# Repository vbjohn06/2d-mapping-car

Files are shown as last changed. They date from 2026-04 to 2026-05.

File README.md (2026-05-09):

# Autonomous Mapping Robot (Differential Drive)

A Mechatronics engineering project designed to navigate a room perimeter autonomously and generate a 2D spatial map. The robot uses custom odometry math and ultrasonic projection to transform raw sensor data into a high-definition car path.

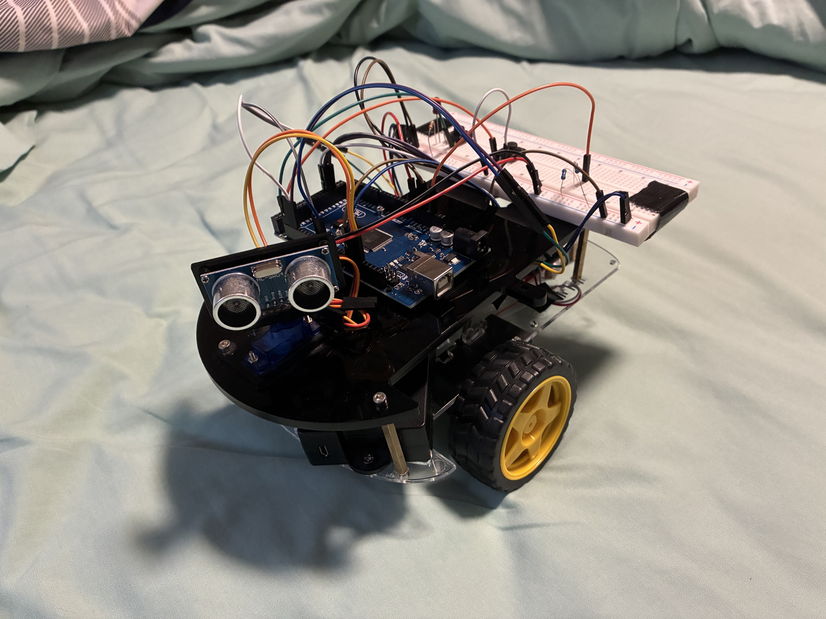
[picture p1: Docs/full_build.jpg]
Image of Car Build
| Robot Build |  |
| :---: | :---: |
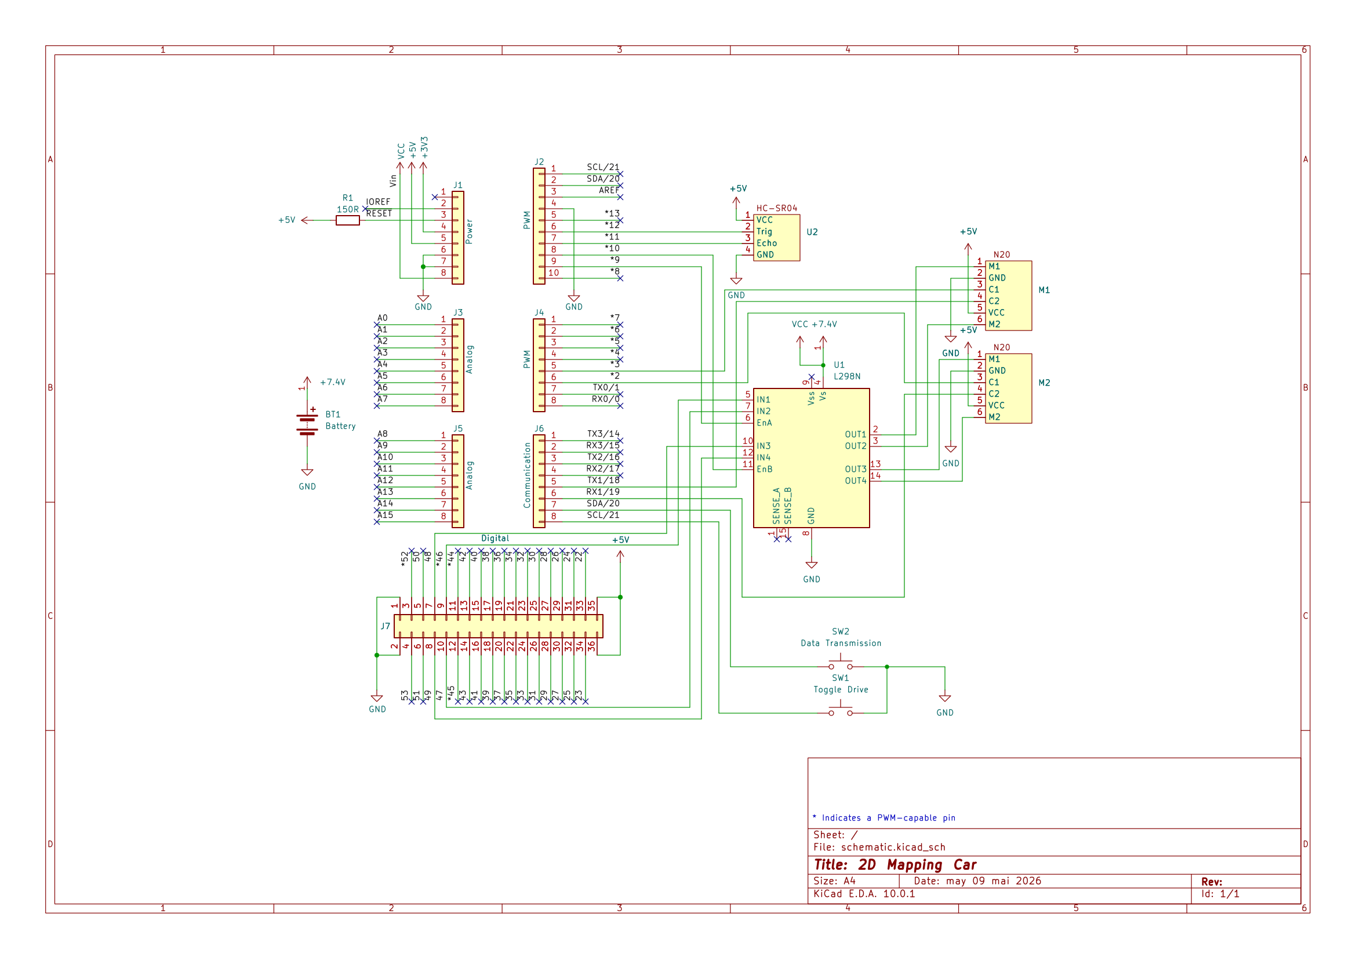
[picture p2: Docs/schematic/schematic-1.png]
Image of Car Schematic
| Robot Schematic |  |
| Live Demo | 2D Mapping Car Demo (https://youtube.com/shorts/CDQi3uIZbc0) |

## 🛠 Features
* **Differential Odometry:** Real-time tracking of $x$, $y$, and $\theta$ (heading) using high-resolution quadrature encoders.
* **Intelligent Wall-Following:** PD-style control logic to maintain a consistent 35cm safety buffer from obstacles using an ultrasonic sensor.
* **Data Logging:** Captures coordinates every 2.5 cm of travel, stored in a 400-point array for USB serial transmission.
* **Self-Correction:** Validated encoder polarity to ensure turns and straight-line distances are calculated with high precision.

---

## 🚀 Hardware Stack
* **Controller:** Arduino MEGA 2560 (ATmega2560)
* **Sensors:** HC-SR04 Ultrasonic Sensor, Dual Quadrature Encoders
* **Communication:** USB Serial Interface (115200 Baud)
* **Chassis:** Two-wheel differential drive (N20 encoder motors driven by L298N driver) with a front swivel caster
* **Power:** 7.4V Li-ion Battery Pack

---

## 💻 Control Logic (Finite State Machine)
The firmware cycles through three primary states to ensure reliable navigation:
1.  **ALIGNING:** Corrects the robot's heading relative to the side wall to maintain the set distance.
2.  **DRIVING:** Executes forward motion while recording points to the internal memory array.
3.  **STUCK:** Detects front-facing obstacles and executes a precision pivot turn to transition to the next wall.

---

## 📂 Project Structure
* `/Arduino`: Contains the `.ino` sketch for motor control, PID alignment, and odometry.
  * **Dependencies**: Requires the `Encoder.h` library by Paul Stoffregen.
  * **Installation**:
    1. Open the **Arduino IDE**.
    2. Go to **Sketch** -> **Include Library** -> **Manage Libraries...**
    3. Search for "Encoder" and look for the version by **Paul Stoffregen**.
    4. Click **Install**.
  * **Hardware Note**: Ensure your encoder pins are connected to interrupt-capable pins (e.g., Pins 2, 3, 18, 19, 20, 21) for the best performance.
* `/Python`: Visualization script to receive Bluetooth data and plot the resulting map using Matplotlib.
  * **Dependencies**: This script requires `matplotlib`, `numpy`, and `pyserial` to function.
  * **Installation**: Open your computer's system terminal (Command Prompt, PowerShell, or Terminal) and run the following command:
      ```bash
      pip install matplotlib numpy pyserial
      ```
* `/Docs`: Technical diagrams for sensor placement and coordinate system geometry.

---

## Technical Difficulties

* **Wireless Communication:** Initially attempted to utilize an **HC-05 Bluetooth module** to stream data and preserve Arduino SRAM. However, the module encountered persistent driver incompatibilities with the host laptop, necessitating a shift in data handling.
* **Hardware Failure:** During hardware integration testing, the **servo motor** controlling the ultrasonic sensor sweep experienced an electrical short. As a result, the sensor is currently in a fixed-forward position for the mapping logic.

---

## How to Run
1. Allow the car to follow the perimeter of the room.
2. Open the `map_plotting.py` file and wait for data transmission.
3. Press the data transmission button on the breadboard.
5. PNG file of the map output should open.

---

## 👤 Author
**Johnny Van Bakel** *Mechatronics Engineering Student* *McMaster University*

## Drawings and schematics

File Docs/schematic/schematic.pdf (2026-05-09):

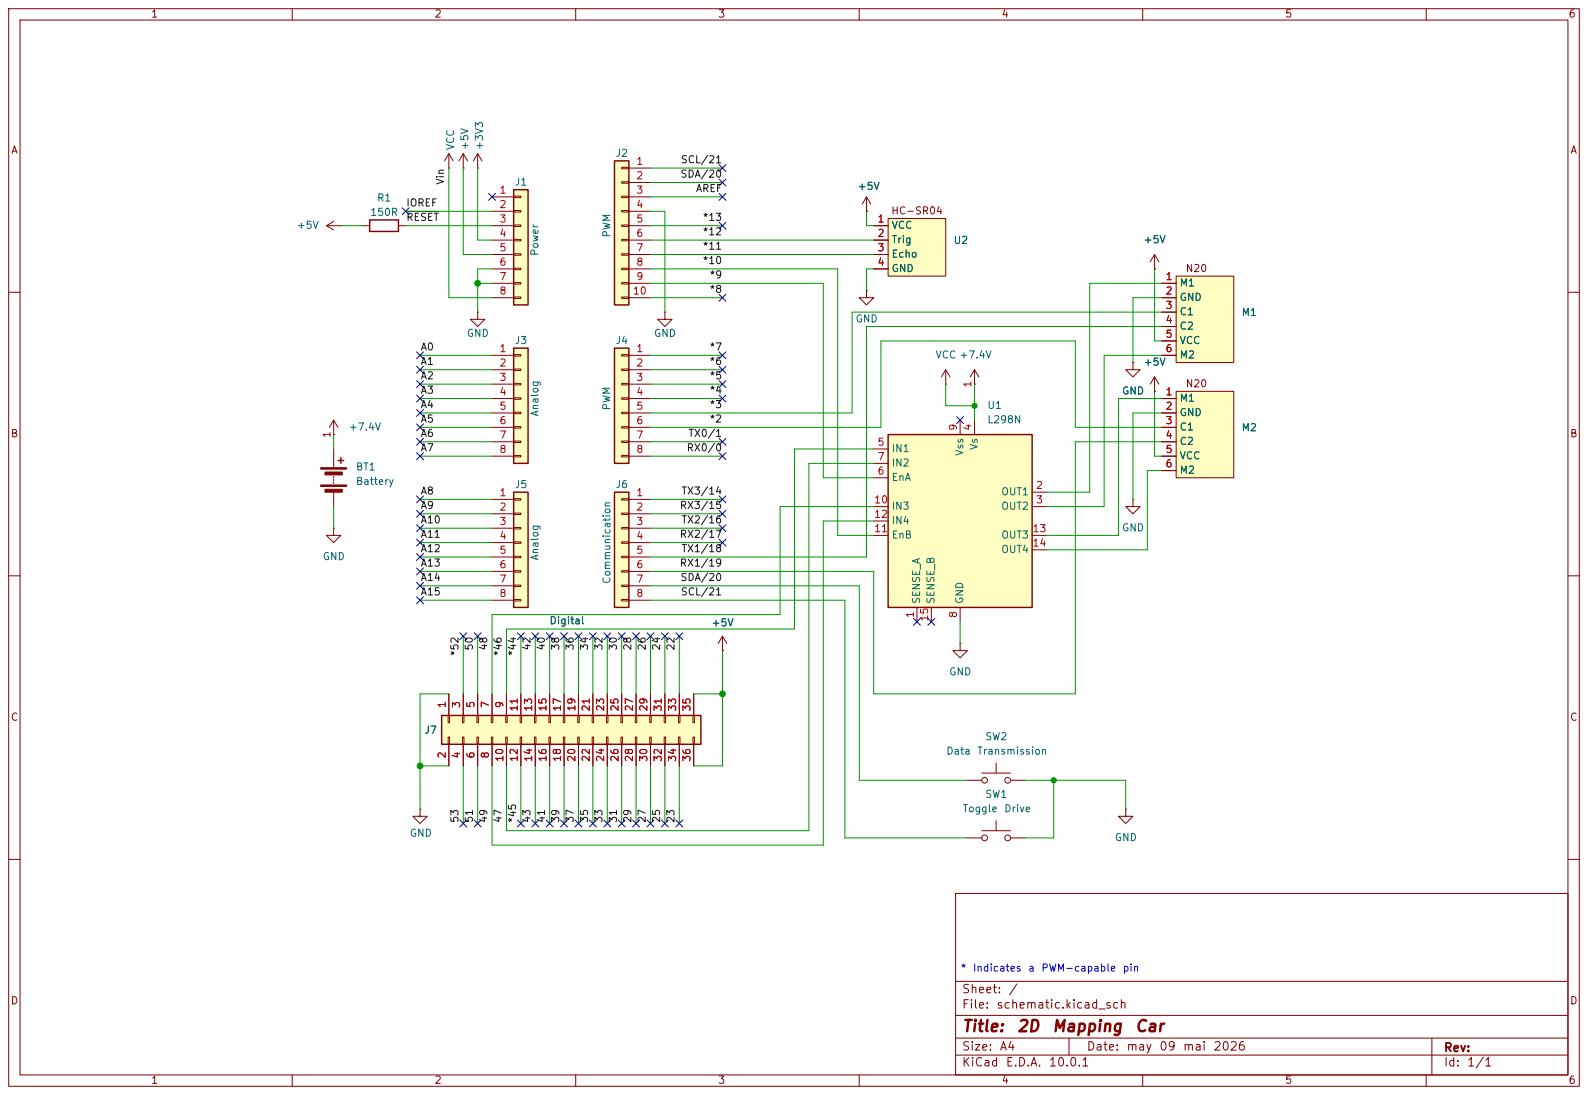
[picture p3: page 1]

*11
*10

GND 12345678

RX1/19
SDA/20
SCL/21

* Indicates a PWM-capable pin +5V

Size: A4 | Rev:
KiCad E.D.A. 10.0.1 | Id: 1/1

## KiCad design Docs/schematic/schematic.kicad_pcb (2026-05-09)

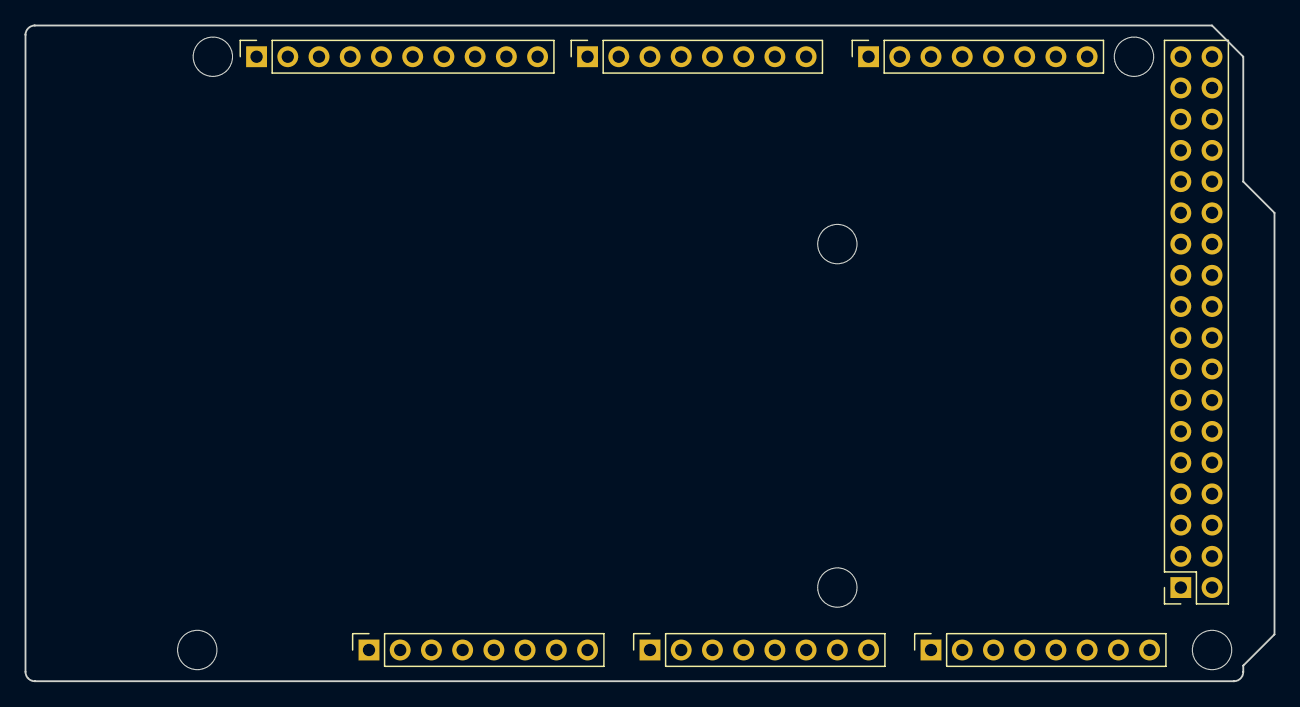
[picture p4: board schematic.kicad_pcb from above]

Board: 2 copper layers, 101.6 x 53.3 mm, 13 parts (0 on the bottom side), 4 nets, no tracks yet.

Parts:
J1: Power; PinSocket_1x08_P2.54mm_Vertical
J2: PWM; PinSocket_1x10_P2.54mm_Vertical
J3, J5: Analog; PinSocket_1x08_P2.54mm_Vertical
J4: PWM; PinSocket_1x08_P2.54mm_Vertical
J6: Communication; PinSocket_1x08_P2.54mm_Vertical
J7: Digital; PinSocket_2x18_P2.54mm_Vertical
MH1, MH2, MH3, MH4, MH5, MH6: MountingHole_3.2mm

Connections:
+5V: J1.5, J7.35, J7.36
/SCL/21: J2.1, J6.8
/SDA/20: J2.2, J6.7
GND: J1.6, J1.7, J2.4, J7.1, J7.2

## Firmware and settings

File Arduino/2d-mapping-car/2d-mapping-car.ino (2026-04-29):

#include <Encoder.h>

/*    Pin Constants   */

// Buttons
const byte BUTTON = 21;
const byte TRANS_BUTTON = 20;



// Ultrasonic sensor
const byte ECHO = 11;
const byte TRIG = 12;
// VCC RED, GND BLUE



// L298N motor driver
const byte IN1 = 46; // Right Motor Forward, BLACK
const byte IN2 = 47; // Right Motor Backward, WHITE
const byte IN3 = 48; // Left Motor Forward, GREY
const byte IN4 = 49; // Left Motor Backward, PURPLE
const byte ENA = 9;  // Right Speed, BROWN
const byte ENB = 10; // Left Speed, BLUE



// Left encoder motor
const byte L_C1 = 3; // GREEN
const byte L_C2 = 18; // YELLOW
Encoder knobLeft(L_C1, L_C2);
long posLeft = -999;
// VCC BLACK, GND BLUE



// Right encoder motor
const byte R_C1 = 2; // GREEN
const byte R_C2 = 19; // YELLOW
Encoder knobRight(R_C2, R_C1);
long posRight = -999;
// VCC BLACK, GND BLUE



/* Calulation Constants */
const int maxSpeed = 100;
float distance = 0;
volatile float closest = 999;
volatile long closestEncoding = 0;
long getPos = 0;

const int setDistance = 35;



/* Boolean Operators */
volatile bool stop = true;
bool hasStarted = false;
bool hasSpun = false;
bool spinStarted = false;
bool transRequested = false;


/* Timers */
unsigned long lastPrint = 0;
const long printInterval = 200;

unsigned long lastDistance = 0;
const long distanceInterval = 30;

unsigned long lastStateChange = 0;

volatile unsigned long lastInterrupt = 0;
const byte DEBOUNCE = 200;

unsigned long lastCheck = 0;



/* Mapping Variables */
float theta = 0;
const int maxPoints = 600;
int point = 1;
float x[maxPoints];
float y[maxPoints];
float xCurrent = 0.0;
float yCurrent = 0.0;

const float base = 13.5;
const float radius = 6.5/2;
const long targetTicks = 4200;

long lastLeft = 0;
long lastRight = 0;

float xLastSaved = 0.0;
float yLastSaved = 0.0;
const float saveThreshold = 2.5; // Save a point every 2.5 cm



/* Debugging Variables */
int printA, printB;



void setup() {
  // 1. Serial for USB and Bluetooth module (HC-05)
  Serial.begin(115200); 
  Serial1.begin(9600); // For Bluetooth Module (that chose to not work)

  // 2. Ultrasonic Sensor Pins
  pinMode(TRIG, OUTPUT);
  pinMode(ECHO, INPUT);

  // 3. L298N Motor Driver Pins
  pinMode(IN1, OUTPUT);
  pinMode(IN2, OUTPUT);
  pinMode(IN3, OUTPUT);
  pinMode(IN4, OUTPUT);
  pinMode(ENA, OUTPUT);
  pinMode(ENB, OUTPUT);

  // 4. Encoder Pins
  pinMode(L_C1, INPUT_PULLUP);
  pinMode(L_C2, INPUT_PULLUP);
  pinMode(R_C1, INPUT_PULLUP);
  pinMode(R_C2, INPUT_PULLUP);

  // 5. Start/Toggle Button
  pinMode(BUTTON, INPUT_PULLUP);
  attachInterrupt(digitalPinToInterrupt(BUTTON), ButtonISR, CHANGE);
  attachInterrupt(digitalPinToInterrupt(TRANS_BUTTON), TransButtonISR, CHANGE);

  // 6. Set origin
  x[0] = 0; y[0] = 0;
}


// Toggles the car's movement
void ButtonISR() {
  unsigned long currentTime = millis();
  if(currentTime - lastInterrupt >= DEBOUNCE) {
    stop = !stop;
    lastInterrupt = currentTime;
  }
}


// Flags for data to be transmitted
void TransButtonISR() {
  unsigned long currentTime = millis();
  if(currentTime - lastInterrupt >= DEBOUNCE) {
    transRequested = true;
    lastInterrupt = currentTime;
  }
}



enum State { 
    IDLE
  , STARTING
  , ANGLING
  , FINDWALL
  , DRIVING
  , STUCK
  , TRANSMITTING
};
State currentState = IDLE;
void (*actions[])() = {
    idle
  , starting
  , angling
  , findwall
  , driving
  , stuck
  , transmitting
};


// Used to track the car's position (cm) and direction (rad)
void updatePosition() {
  long currentLeft = knobLeft.read(); 
  long currentRight = knobRight.read();

  // 1. Calculate change in distance for each wheel (cm)
  float cm_per_tick = (2.0 * PI * radius) / targetTicks;
  float dL = (currentLeft - lastLeft) * cm_per_tick;
  float dR = (currentRight - lastRight) * cm_per_tick;

  // 2. Save current counts for next iteration
  lastLeft = currentLeft;
  lastRight = currentRight;

  // 3. Calculate linear and angular displacement
  float dS = (dR + dL) / 2.0;
  float dTheta = (dR - dL) / base;

  // 4. Update Pose (X, Y, Theta)
  // Using (theta + dTheta/2) provides better accuracy during turns
  xCurrent += dS * cos(theta + (dTheta / 2.0));
  yCurrent += dS * sin(theta + (dTheta / 2.0));
  theta += dTheta;

  // 5. Keep theta between -PI and PI
  if (theta > PI) theta -= 2 * PI;
  if (theta < -PI) theta += 2 * PI;
}


// Main loop
void loop() {
  updatePosition();

  // Constantly looping through the current state.
  actions[currentState]();

  // This block of code is what saves the car's location over time.
  if(point < maxPoints) {
    
    // Calculate how far we've moved from the last "outline" point.
    float distSinceSave = sqrt(pow(xCurrent - xLastSaved, 2) + pow(yCurrent - yLastSaved, 2));

    if(distSinceSave >= saveThreshold) {
      x[point] = xCurrent;
      y[point] = yCurrent;
      
      xLastSaved = xCurrent;
      yLastSaved = yCurrent;
      point++;
    }
  }

  // Debugging
  getDistance();
  if(!stop && millis() - lastPrint >= printInterval) {
    Serial.print("Distance: ");
    Serial.print(distance);
    Serial.print("\t\tState: ");
    Serial.print(currentState);
    Serial.print("\t\tLeft Speed: ");
    Serial.print(printB);
    Serial.print("\t\tRight Speed: ");
    Serial.println(printA);
    lastPrint = millis();
  }
}


// Car is not moving
void idle() {
  stopMoving();

  if(!stop) {
    currentState = STARTING;
    lastStateChange = millis();
  } else if (transRequested) {
    transRequested = false; // "Catch" and reset the flag
    currentState = TRANSMITTING;
    Serial.println("Entering Transmission Mode...");
  }
}


// The car's starting operation
void starting() {
  if(stop) {
    currentState = IDLE;
    return;
  }

  getDistance();
  // Wait a second before either Driving or Aligning
  if(millis() - lastStateChange >= 1000) {
    if(distance < setDistance + 10) {
      currentState = DRIVING;
      return;
    } else {
      lastStateChange = millis();
      currentState = ANGLING;
    }
  }
}


// Aligns the car to the nearest wall
void angling() {
  if(stop) { currentState = IDLE; spinStarted = false; return; }

  // Sets variables once
  if(!spinStarted) {
    getPos = knobRight.read();
    closest = 999; // Reset closest distance
    spinStarted = true;
    hasSpun = false;
  }

  getDistance();
  // PHASE 1: SCANNING
  if(!hasSpun) {
    if(abs(getPos - knobRight.read()) > (targetTicks * 2)) {
      hasSpun = true;
      stopMoving(); // This includes a 200ms delay and resets pins
      return; // Exit and wait for the next loop to start Phase 2
    }
    
    // Power CW until finished
    analogWrite(ENB, 70); digitalWrite(IN3, HIGH); digitalWrite(IN4, LOW);
    analogWrite(ENA, 70); digitalWrite(IN1, LOW);  digitalWrite(IN2, HIGH);
    printA = -50; printB = 50;

    if(distance < closest && distance > 0) {
      closest = distance;
      closestEncoding = knobRight.read();
    }
  }
  // PHASE 2: ALIGNING
  else {
    long currentPos = knobRight.read();
    // Increase the buffer to 300 to account for momentum at speed 50
    if(currentPos > closestEncoding + 1500) { // CCW
      analogWrite(ENB, 70); digitalWrite(IN3, HIGH); digitalWrite(IN4, LOW);
      analogWrite(ENA, 70); digitalWrite(IN1, LOW); digitalWrite(IN2, HIGH);
    } else if(currentPos < closestEncoding) { // CW
      analogWrite(ENB, 70); digitalWrite(IN3, LOW); digitalWrite(IN4, HIGH);
      analogWrite(ENA, 70); digitalWrite(IN1, HIGH);  digitalWrite(IN2, LOW);
    } else {
      hardBrake();
      currentState = FINDWALL;
      spinStarted = false; // Reset for future use
      hasSpun = false;
      delay(500);
    }
  }
}


// Travels straight in aligned direction
void findwall() {
  if(stop) {
    currentState = IDLE;
    return;
  }
  
  getDistance();
  if(distance > setDistance + 10) {
    // Right Motor
    analogWrite(ENA, maxSpeed);
    digitalWrite(IN1, HIGH);
    digitalWrite(IN2, LOW);

    // Left Motor
    analogWrite(ENB, maxSpeed);
    digitalWrite(IN3, HIGH);
    digitalWrite(IN4, LOW);
    
    // Print Settings
    printA = maxSpeed; printB = maxSpeed;
  } else {
    currentState = DRIVING;
  }
}


// Handles car's main driving functions
void driving() {
  if(stop) {
    currentState = IDLE;
    return;
  }

  getDistance();
  if(distance < 15 && distance > 0) { // back up right if stuck
    stopMoving();
    currentState = STUCK;
  } else if(distance < setDistance-1.5) { // turn right
    int speedA = constrain(maxSpeed - (setDistance-1.5 - distance)*10, 50, maxSpeed);
    analogWrite(ENA, speedA); 
    analogWrite(ENB, maxSpeed);
    digitalWrite(IN1, HIGH); digitalWrite(IN2, LOW); // Ensure direction
    printA = speedA; printB = maxSpeed; 
  } else if(distance > setDistance+1.5) { // turn left
    int speedB = constrain(maxSpeed - (distance - setDistance+1.5)*10, 50, maxSpeed);
    analogWrite(ENB, speedB);
    analogWrite(ENA, maxSpeed);
    digitalWrite(IN3, HIGH); digitalWrite(IN4, LOW); // Ensure direction
    printB = speedB; printA = maxSpeed;
  } else {
    // Straight
    analogWrite(ENA, maxSpeed);
    analogWrite(ENB, maxSpeed);
    printA = maxSpeed; printB = maxSpeed;
  }
}


// If the car is in close proximity to walls
void stuck() {
  if(stop) { currentState = IDLE; return; }

  // 1. Initialize the timer only ONCE when entering this state
  static unsigned long stuckStartTime = 0;
  if (stuckStartTime == 0) stuckStartTime = millis();

  getDistance();

  // 2. Movement: Back up and Pivot
  // Right back (100), Left back (60)
  analogWrite(ENA, 100); digitalWrite(IN1, LOW); digitalWrite(IN2, HIGH);
  analogWrite(ENB, 60);  digitalWrite(IN3, LOW); digitalWrite(IN4, HIGH);
  printA = -100; printB = -60;

  // 3. Exit Condition (Wait 1.2 seconds to ensure clearance)
  if (millis() - stuckStartTime > 1200) {
    // Reset timer for next time
    stuckStartTime = 0;
    
    // 4. Move forward straight for a moment to "reset" the robot's heading
    // This prevents it from immediately hooking back into the wall
    analogWrite(ENA, 80); digitalWrite(IN1, HIGH); digitalWrite(IN2, LOW);
    analogWrite(ENB, 80); digitalWrite(IN3, HIGH); digitalWrite(IN4, LOW);
    delay(300); 
    
    currentState = DRIVING;
  }
}


// Transmitting of the data
void transmitting() {
  // If the user un-toggles the stop button, go back to IDLE
  if (!stop) {
    currentState = IDLE;
    return;
  }

  // Loop through all points that have been recorded (up to 'point')
  for(int i = 0; i < point; i++) {
    Serial.print(x[i]);
    Serial.print(",");
    Serial.println(y[i]);
    
    // Give the Serial buffer time to send data (approx 10-15ms)
    delay(10); 
  }

  Serial.println("END_DUMP");

  // Reset the trigger and go back to IDLE
  transRequested = false;
  currentState = IDLE;
}


// Uses the HC-SR04 to find distance from wall
float getDistance() {
  if(stop) return;
  if(millis() - lastDistance >= distanceInterval) {

    digitalWrite(TRIG, LOW);
    delayMicroseconds(2);
    digitalWrite(TRIG, HIGH);
    delayMicroseconds(10);
    digitalWrite(TRIG, LOW);

    long duration = pulseIn(ECHO, HIGH, 30000); // 30ms timeout prevents freezing
    distance = (duration * 0.0343) / 2;

    lastDistance = millis();

  }
}


// Stops car with a coast
void stopMoving() {
  analogWrite(ENA, 0);
  analogWrite(ENB, 0);
  delay(200);
  digitalWrite(IN1, LOW);
  digitalWrite(IN2, LOW);
  digitalWrite(IN1, LOW);
  digitalWrite(IN2, LOW);
}


// Stops car quickly
void hardBrake() {
  digitalWrite(IN1, HIGH); digitalWrite(IN2, HIGH);
  digitalWrite(IN3, HIGH); digitalWrite(IN4, HIGH);
  analogWrite(ENA, 255); // Full "holding" power for a split second
  analogWrite(ENB, 255);
}

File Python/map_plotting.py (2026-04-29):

import matplotlib.pyplot as plt
import numpy as np
import serial
import os

# FORCE Python to look in the correct folder
try:
    os.chdir(os.path.dirname(os.path.abspath(__file__)))
except:
    pass 

try:
    # Creating serial ID
    ser = serial.Serial('COM6', 115200)
    ser.reset_input_buffer() # Clear any old junk
    x_points = []
    y_points = []

    # Replace the file reading logic with Serial reading logic
    print("Waiting for Arduino data...")
    while True:
        # Read the line once and store it
        raw_line = ser.readline().decode('utf-8', errors='ignore').strip()
        
        # Check if we should stop
        if raw_line == "END_DUMP":
            print("Received END_DUMP signal.")
            break
            
        # If it's a coordinate, process it
        if "," in raw_line:
            try:
                parts = raw_line.split(",")
                x_val = float(parts[0])
                y_val = float(parts[1])
                x_points.append(x_val)
                y_points.append(y_val)
                print(f"Received: {x_val}, {y_val}")
            except (ValueError, IndexError):
                continue
            
    # Save data with quicker array type
    x_arr = np.array(x_points)
    y_arr = np.array(y_points)

    # Plot graph
    plt.figure(figsize=(10, 8))
    plt.plot(x_arr, y_arr)
    plt.title("Arduino Sensor Map")
    plt.grid(True)
    
    # Save and open image
    image_path = 'my_map_output.png'
    plt.savefig(image_path, dpi=300)
    print("Map saved successfully!")
    plt.show()
    os.startfile(image_path)

except Exception as e:
    print(f"\nCRITICAL ERROR: {e}")

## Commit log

2026-04-29 Update README with technical difficulties and chassis details
    Added technical difficulties section and updated chassis description.
2026-05-09 Adding all schematic files
    [schematic.kicad_pcb, schematic.kicad_sch]
2026-05-09 Add robot schematic image to README
2026-05-09 Fix table formatting in README.md
    Removed duplicate Robot Schematic entry in the table.
2026-05-09 Fix robot schematic link in README
    Updated the link for the robot schematic image to point to a PDF file.
2026-05-09 Added PNG of schematic
2026-05-09 Update robot schematic image format in README
2026-05-09 Update schematic image in README.md
